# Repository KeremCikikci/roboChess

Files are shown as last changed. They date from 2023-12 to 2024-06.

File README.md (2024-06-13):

# RoboChess

vlcsnap-2023-12-28-12h02m27s572

https://www.youtube.com/watch?v=UMYv8-Q6y2Y
 
Each frame captured by the camera undergoes various processes to eliminate proportional distortions and noise. In the obtained output, each frame is observed individually and converted from BGR format to HSV format.

To reduce errors, colors of chess pieces that are far apart in the spectrum are made more distinguishable through different processes. Thus, the colors of the pieces on all squares are recorded. Since the positions of the pieces are known at the beginning of a chess game, there is no need to determine the types of pieces from the captured image.

For a chess game played on an online platform like Lichess, a unique ID is assigned to the game, and necessary information is retrieved using the Lichess API. However, to prevent cheating attempts, the Lichess API provides move information with a delay. Therefore, in a Lichess game, when a change occurs, a screenshot is taken to detect the move. Moves are recorded in the UCI (Universal Chess Interface) notation, which specifies the starting and ending coordinates of the pieces.

Additionally, the pieces obtained from Lichess at the beginning of the game are compared with the pieces detected in the squares from the camera. If they are not in sync, differing square coordinates are marked. When it's a player's turn, data flow is monitored from the Arduino, and if the button is pressed, the camera observes the pieces in the squares again. By identifying the differing pieces from the previously saved content, it's determined whether any piece has been captured. Then, a move notation is created in UCI format, and the move's validity is checked. The move is sent to the Lichess game with the assigned ID using the Lichess API. Additionally, time information obtained from the API is sent to Arduino via the Serial port.

At the start of each game, motors rotate until switches are triggered, bringing the robot arm to its home position. This resets all angle values and motors, enabling the robot arm to move to the desired coordinate in subsequent commands. After the home position, the arm moves to a waiting position. A function written in the Arduino code determines the slowest and fastest motor values on the arm, as well as the instantaneous speed during the motor's duty cycle, using a mathematical function.

While power is transmitted via a pulley on the X-axis, reducers are used on the Y and Z axes to greatly reduce the motor's speed and increase its torque by about 60 times. These reducers allow smooth movement of the load motors without excessive force.

In the final arm segment of the robot, there is a structure that lifts the chess pieces using a funnel. When triggered in the center of the funnel, a coil creates a magnetic field to lift the pieces by attracting the screws on top of them. Due to the high current drawn by the coil, it's triggered by a relay.

In the program, the chessboard is considered a coordinate axis, and after providing the coordinates where only the farthest point of the arm will be, the most economical angle values for the arm to reach the desired location are calculated. Motors bring the robot to the calculated angle values.

The movement path of the arm is determined by the move notation sent from the Serial monitor. When the arm movement is complete, it notifies the Python program. Additionally, time information is conveyed throughout the game. The remaining time of the opponents is visualised on displays. While each LED control of the displays requires 20 separate data wires, with 2 shift register chips, the data is transmitted using only 3 wires. The shift registers sequentially light up the required LEDs in each segment of the display. This process happens so quickly that the human eye perceives the LEDs as lit simultaneously.

## Run RoboChess
Install the necessary packages before running the code.
```
pip install -r requirements.txt
```

Before running the code, Arduino Uno must be connected to the computer and the `main.py` file must be configured.

+ Connect Arduino to your computer and specify its port
`ARDUINO_PORT = <your_arduino_port>`
+ Create a game from Lichess and assign the game link to the code.
`GAME_ID = <your_game_id>`
+ Position an external camera to see the chessboard and connect the camera to your computer.

Run the main code in the directory where you downloaded the repository.
```
python main.py
```

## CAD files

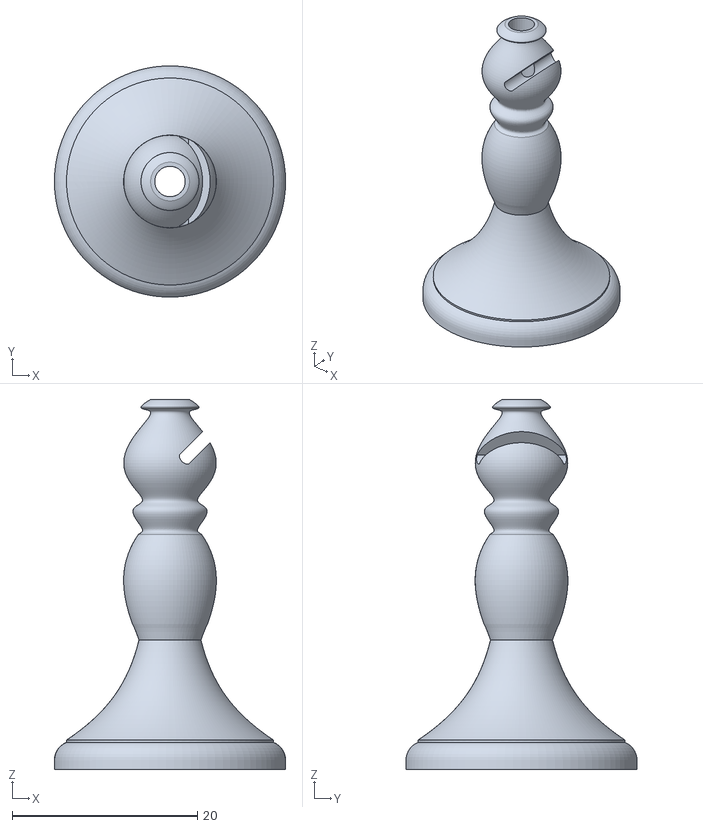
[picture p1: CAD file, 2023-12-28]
3D/chess_pieces/bishop.stl
25.0 x 25.0 x 40.0

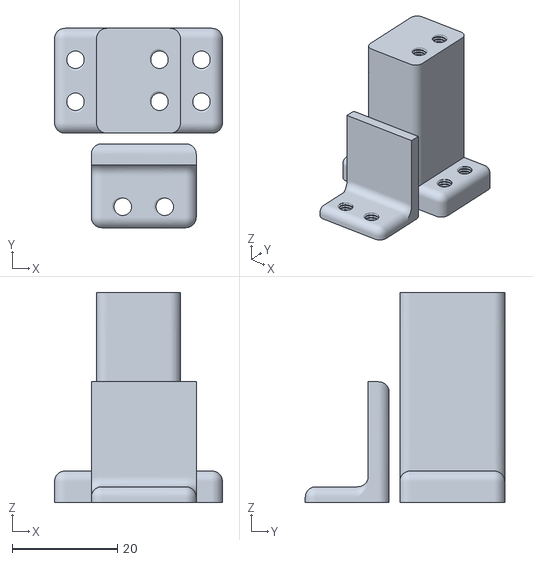
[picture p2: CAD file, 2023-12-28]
3D/main_elements/switchX_holder.stl
32.0 x 38.0 x 40.0

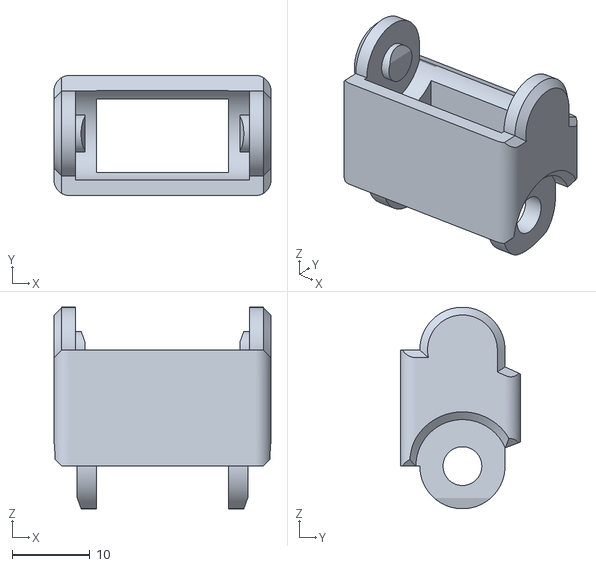
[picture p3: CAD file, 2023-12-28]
3D/others/cable_channel.stl
28.0 x 15.5 x 26.0

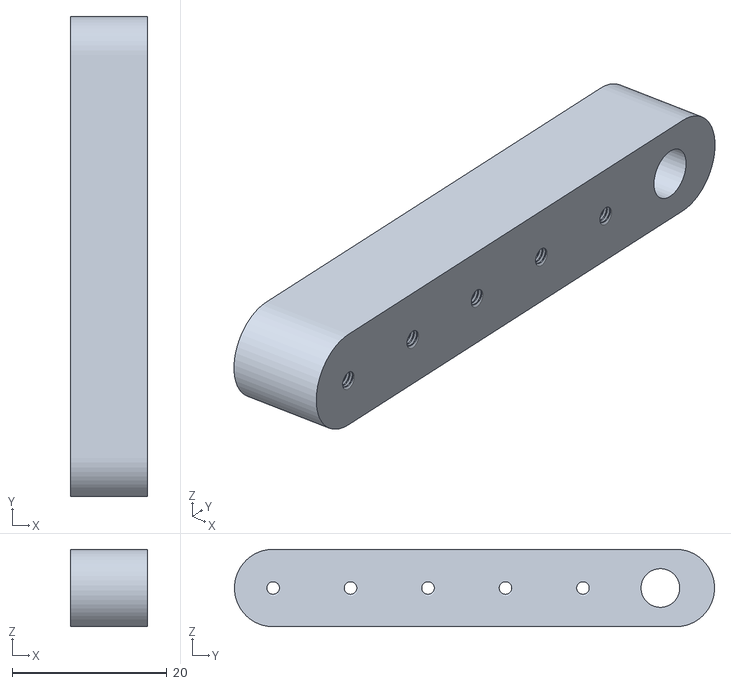
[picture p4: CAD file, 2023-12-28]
3D/reducer/radius1.stl
10.0 x 62.0 x 10.00

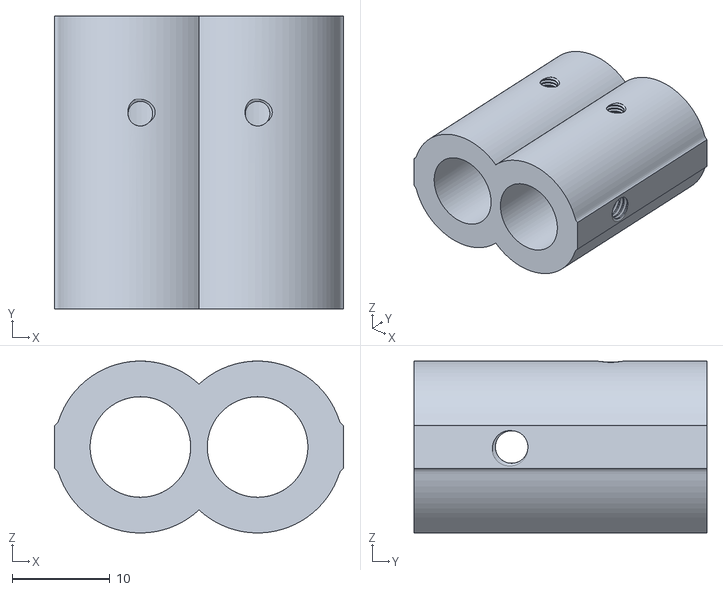
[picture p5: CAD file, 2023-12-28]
3D/third_arm/pipe_stabilizer.stl
29.6 x 30.0 x 17.6

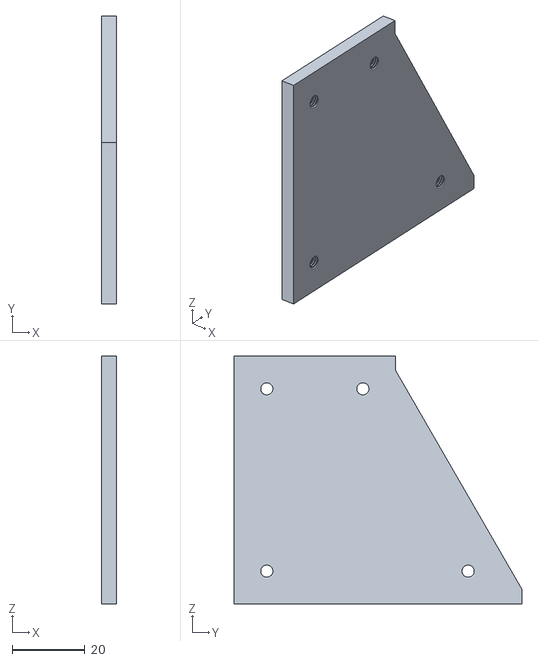
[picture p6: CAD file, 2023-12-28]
3D/watch_box/left.stl
4.00 x 79.0 x 68.0

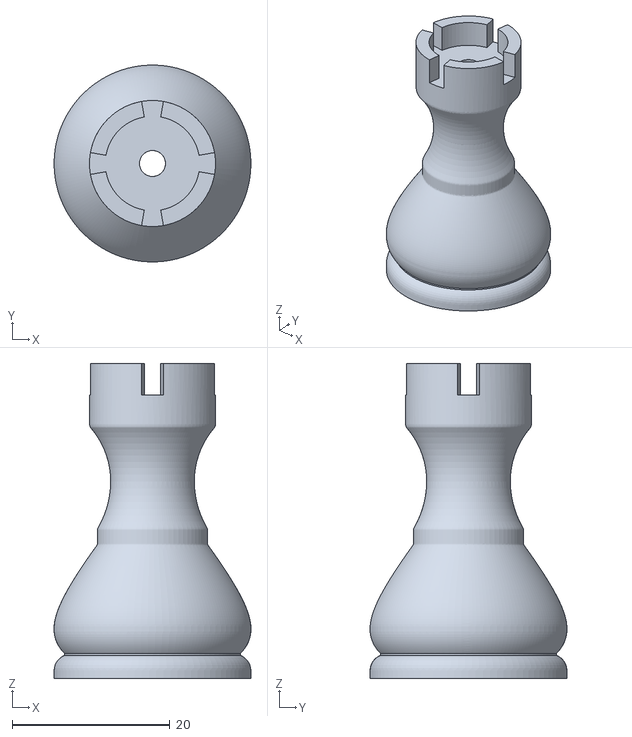
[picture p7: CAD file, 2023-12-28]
3D/chess_pieces/rook.stl
25.0 x 25.0 x 40.0

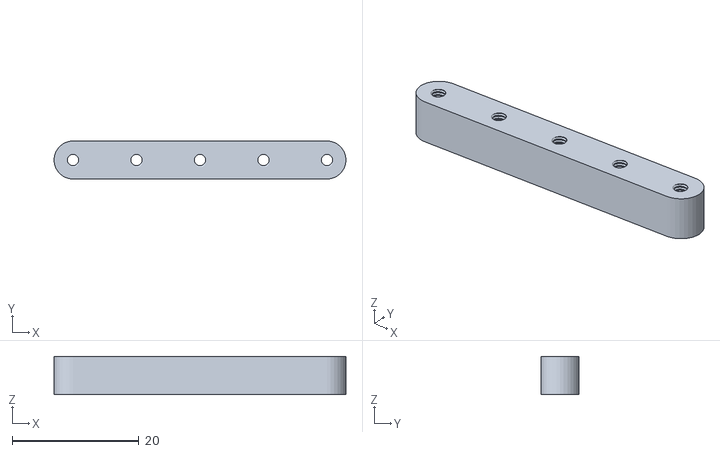
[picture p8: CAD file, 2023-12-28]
3D/main_elements/wire3.stl
46.0 x 6.00 x 6.00

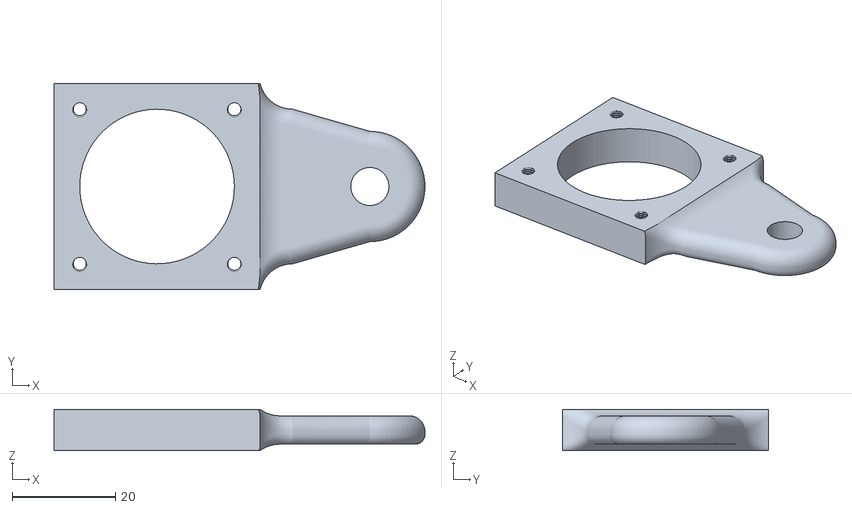
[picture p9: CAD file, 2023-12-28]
3D/others/cam_holder.stl
72.0 x 40.0 x 8.00

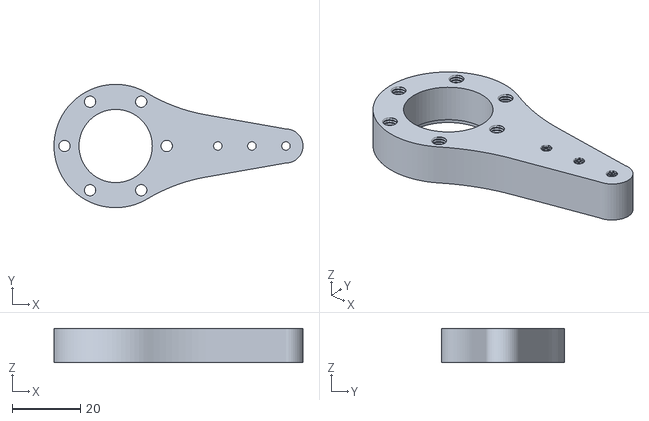
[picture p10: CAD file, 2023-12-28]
3D/reducer/reducer_out.stl
73.1 x 36.2 x 10.0

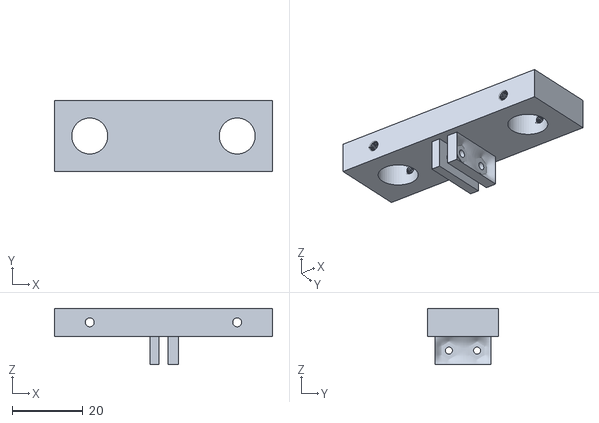
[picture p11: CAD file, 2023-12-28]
3D/third_arm/housing.stl
61.8 x 20.0 x 16.0

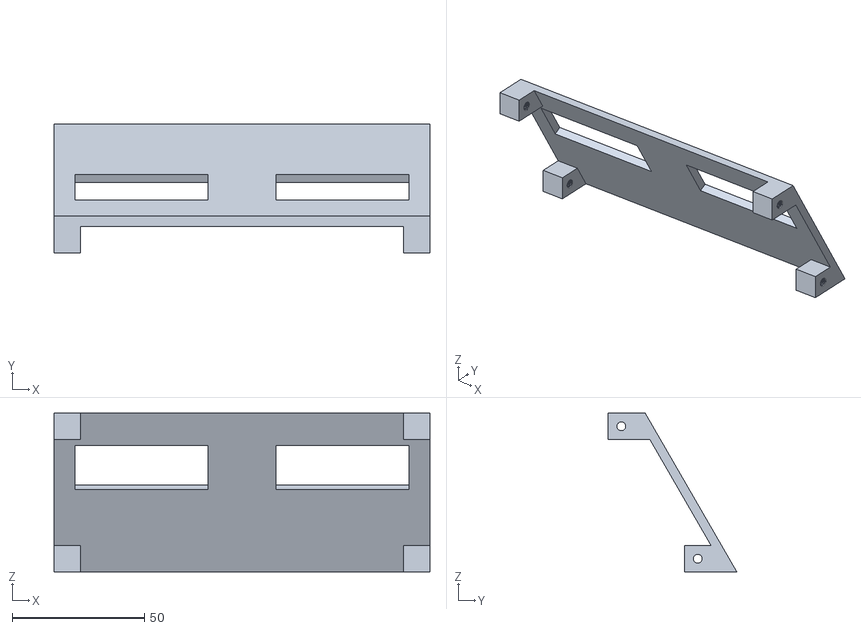
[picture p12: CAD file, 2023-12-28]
3D/watch_box/front.stl
142.0 x 48.6 x 60.0

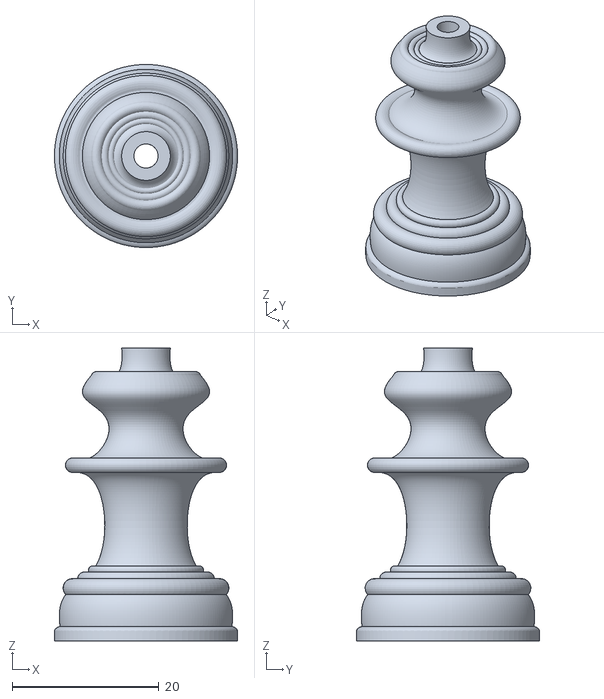
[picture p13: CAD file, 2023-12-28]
3D/chess_pieces/queen.stl
25.0 x 25.0 x 40.0

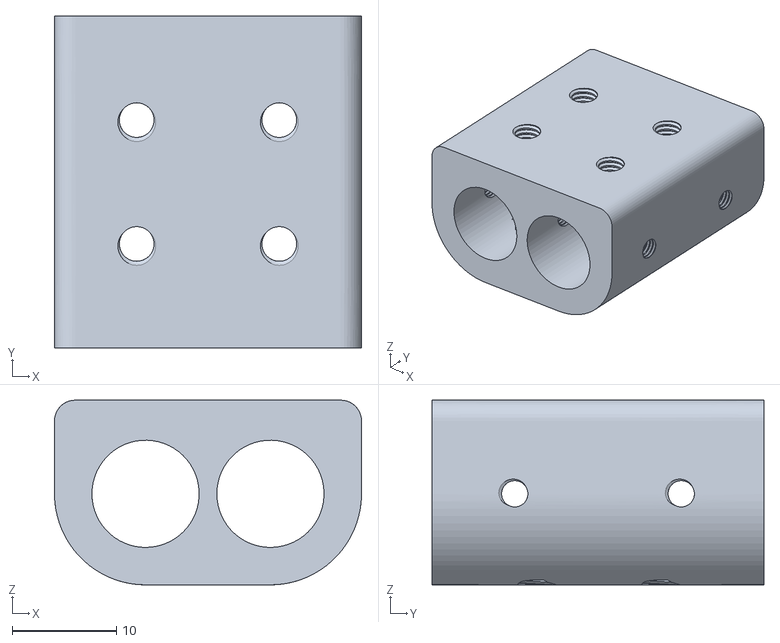
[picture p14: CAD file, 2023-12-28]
3D/main_elements/servo_base.stl
29.5 x 31.9 x 17.8

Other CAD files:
3D/others/light_holder.stl
3D/reducer/bpl.stl
3D/third_arm/coupling.stl
3D/watch_box/top.stl
3D/chess_pieces/king.stl
3D/chess_pieces/knight.stl
3D/chess_pieces/pawn.stl
3D/main_elements/base.stl
3D/main_elements/lower_bearing_seat.stl
3D/main_elements/nema17_holder v1.stl
3D/main_elements/nema17_holder v2.stl
3D/main_elements/nema17_holder v3.stl
3D/main_elements/pipe_stabilizer.stl
3D/main_elements/shaft_seat.stl
3D/main_elements/switchX_holder_top v2.stl
3D/main_elements/switchYholder.stl
3D/main_elements/top_bearing_seat.stl
3D/main_elements/wire.stl
3D/main_elements/wire2.stl
3D/main_elements/wire_holder.stl
3D/old_chess_pieces/bishop.stl
3D/old_chess_pieces/knight.stl
3D/old_chess_pieces/queen.stl
3D/old_chess_pieces/rook.stl
3D/old_gripper/gripper1 (1) v1.stl
3D/old_gripper/gripper1 (1) v8.stl
3D/old_gripper/gripper2 (1) v1.stl
3D/old_gripper/gripper2 (1) v3.stl
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

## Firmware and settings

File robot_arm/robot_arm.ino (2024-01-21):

#include <Servo.h>
Servo w;

#define dsP 13
#define latchP A5
#define clockP A4
#define button 12

#define gripper 8

#define dirX  2
#define pulseX 5
#define switchX A3
#define dirY 6
#define pulseY 7
#define switchY A1
#define dirZ  10
#define pulseZ 11
#define switchZ A2

boolean rotX = false; // false: go0
boolean rotY = true; // false: go0
boolean rotZ = true; // false: go0

double SPMX = 10.1;//9.5; // 9.75, 8.5
double SPDY = 28.89;//28.89
double SPDZ = 28.89;

double posX;
double angleA = 0;
double angleB = 0;
double angleC = 90;

int squaresA[8];
int squaresB[8];

int servoBost = 10;

int aAngles_[8][2] = {{118, 82}, {105, 74}, {95, 69}, {85, 62}, {78, 54}, {75, 46}, {60, 40}, {52, 30}};
int bAngles_[8][2] = {{45, 29}, {55, 43}, {55, 55}, {67, 66}, {82, 80}, {95, 93}, {115, 105}, {119, 117}};
int servoBosts[8] = {20, 18, 17, 12, 12, 10, 8, 10};

String alphabet[8] = {"a", "b", "c", "d", "e", "f", "g", "h"};

String move_ = "None";
String capture_ = "None";
String first, second, third, fourth;
int num1, num2;
double squareSize = 40;
double rightPadding = 40L;

String data;

unsigned int digits[8] = {32927, 16421, 8205, 4249, 2121, 1089, 539, 257};/*{0, 0, 0, 0, 0, 0, 0, 0};*/

String strBinDig;
String clock_;
String message;

String firstClock;
String secondClock;

boolean turn = true;

unsigned long previousMillis = 0;
const unsigned long interval = 1000;

String segments[10] = {
  "0000001", // 0
  "1001111", // 1
  "0010010", // 2
  "0000110", // 3
  "1001100", // 4
  "0100100", // 5
  "0100000", // 6
  "0001111", // 7
  "0000000", // 8
  "0000100"  // 9
};


void go0(int delay_){
  w.write(120);
  rotX = false; // false: go0
  rotY = false; // false: go0
  rotZ = false; // false: go0

  boolean switchXValue;
  boolean switchYValue;
  boolean switchZValue;
  
  digitalWrite(dirX, rotX);
  digitalWrite(dirY, rotY);
  digitalWrite(dirZ, rotZ);

  for(int i = 0; i < (int)(30 * SPDY); i++){
    switchYValue = digitalRead(switchY);
    digitalWrite(pulseY, 1);
    delayMicroseconds(delay_);
    digitalWrite(pulseY, 0);
    delayMicroseconds(delay_);

    if (switchYValue == 1)
      break;
  }
  
  while (true){
    switchXValue = digitalRead(switchX);
    switchYValue = digitalRead(switchY);
    switchZValue = digitalRead(switchZ);
    
    if (switchXValue == 0)
      digitalWrite(pulseX, 1);
      
    if (switchYValue == 0)
      digitalWrite(pulseY, 1);
    
    if (switchZValue == 0)
      digitalWrite(pulseZ, 1);
    
    delayMicroseconds(delay_);
    if (switchXValue == 0)
      digitalWrite(pulseX, 0);
    
    if (switchYValue == 0)
      digitalWrite(pulseY, 0);
    
    if (switchZValue == 0)
      digitalWrite(pulseZ, 0);
    
    if ((switchXValue == 1) && (switchYValue == 1) && (switchZValue == 1)){
      posX = 0;
      angleA = 123.7;//143.3
      angleB = 119;//108
      angleC = 90;

      break;
    }
    delayMicroseconds(delay_);
  }
  w.write(90);
}

int findMax(int a, int b, int c) {
  int maxVal = a;

  if (b > maxVal) {
    maxVal = b;
  }

  if (c > maxVal) {
    maxVal = c;
  }

  return maxVal;
}

void goPos(double xPosToGo, double aAngleToGo, double bAngleToGo, int minSpeed, int maxSpeed, int servoBost = 0){
  double deltaPosX = posX - xPosToGo;
  double deltaAngleA = angleA - aAngleToGo;
  double deltaAngleB = angleB - bAngleToGo;
  
  double posX_ = posX;
  double angleA_ = angleA;
  double angleB_ = angleB;
  
  int stepsX = abs(deltaPosX * SPMX);
  int stepsA = abs(deltaAngleA * SPDY);
  int stepsB = abs(deltaAngleB * SPDZ);

  int maxStep = findMax(stepsX, stepsA, stepsB);
  
  int steppedX = 0;
  int steppedA = 0;
  int steppedB = 0;
  
  double steppedAngleA = 0;
  double steppedAngleB = 0;

  rotX = true;
  rotY = false;
  rotZ = false;

  if (deltaPosX > 0)
    rotX = false;
  if (deltaAngleA > 0)
    rotY = true;
  if (deltaAngleB > 0)
    rotZ = true;

  digitalWrite(dirX, rotX);
  digitalWrite(dirY, rotY);
  digitalWrite(dirZ, rotZ);
    
  int phrase = 1;
  
  int lengthOfPhrase1 = maxStep/3;
  int lengthOfPhrase3 = maxStep/3;
  
  int delay_;

  int counter = 0;
  
  while (true){
    unsigned long currentMillis = millis();
    
    boolean switchXValue = digitalRead(switchX);
    boolean switchYValue = digitalRead(switchY);
    boolean switchZValue = digitalRead(switchZ);
/*
    if (((switchXValue == 1) || (switchYValue == 1) || (switchZValue == 1)) && (counter > 2000)){
      go0(500);
      break;
    }*/

    if (currentMillis - previousMillis >= interval) {
    previousMillis = currentMillis;

    if (turn == false){
      firstClock = String(firstClock.toInt()-1);
      int zeros = 4 - firstClock.length();
      for (int i = 0; i < zeros; i++){
        firstClock = "0" + firstClock;
      }
    }
    else{
      secondClock = String(secondClock.toInt()-1);
      int zeros = 4 - secondClock.length();
      for (int i = 0; i < zeros; i++){
        secondClock = "0" + secondClock;
      }
    }
    clock_ = formatTime(firstClock.toInt()) + formatTime(secondClock.toInt());
    formatClock();
  }
  
    counter++;
    
    stepsX--;
    stepsA--;
    stepsB--;

    if ((steppedX > maxStep - lengthOfPhrase3) || (steppedA > maxStep - lengthOfPhrase3) || (steppedB > maxStep - lengthOfPhrase3))
      phrase = 3;
    else if ((steppedX > lengthOfPhrase1) || (steppedA > lengthOfPhrase1) || (steppedB > lengthOfPhrase1))
      phrase = 2;

    if (phrase == 3)
      delay_ = map(counter, maxStep - lengthOfPhrase3, maxStep, maxSpeed, minSpeed);
    if (phrase == 2)
      delay_ = maxSpeed;
    if (phrase == 1)
      delay_ = map(counter, 0, lengthOfPhrase1, minSpeed, maxSpeed);
    
    if (stepsX >= 0){
      digitalWrite(pulseX, 1); 
    }
       
    if (stepsA >= 0){
      digitalWrite(pulseY, 1);
    }
      
    if (stepsB >= 0){
      digitalWrite(pulseZ, 1);
    }
      
    delayMicroseconds(delay_);

    if (stepsX >= 0){
      digitalWrite(pulseX, 0);
      steppedX++;
    }
    if (stepsA >= 0){
      digitalWrite(pulseY, 0);
      steppedA++;
    }
    if (stepsB >= 0){
      digitalWrite(pulseZ, 0);
      steppedB++;
    }
    
    if ((stepsX < 0) && (stepsA < 0) && (stepsB < 0)){
      posX = xPosToGo;
      angleA = aAngleToGo;
      angleB = bAngleToGo;
      
      break;
    }

    steppedAngleA = steppedA / SPDY;
    steppedAngleB = steppedB / SPDZ;

    if (rotX == false)
      posX = posX + steppedX;
    else
      posX = posX - steppedX;
      
    if (rotY == false)
      angleA = angleA_ + steppedAngleA;
    else
      angleA = angleA_ - steppedAngleA;

    if (rotZ == false)
      angleB = angleB_ + steppedAngleB;
    else
      angleB = angleB_ - steppedAngleB;

    angleC = 270 - angleA - angleB;

    if ((angleC > 60) && (angleC < 160))
      w.write(angleC + servoBost);
      //Serial.println(angleC);
    delayMicroseconds(delay_);
  }
  posX = xPosToGo;
  angleA = aAngleToGo;
  angleB = bAngleToGo;
}
void goPos2(double xPosToGo, double aAngleToGo, double bAngleToGo, int minSpeed, int maxSpeed, int servoBost = 0){
  double deltaPosX = posX - xPosToGo;
  double deltaAngleA = angleA - aAngleToGo;
  double deltaAngleB = angleB - bAngleToGo;
  
  double posX_ = posX;
  double angleA_ = angleA;
  double angleB_ = angleB;
  
  int stepsX = abs(deltaPosX * SPMX);
  int stepsA = abs(deltaAngleA * SPDY);
  int stepsB = abs(deltaAngleB * SPDZ);

  int maxStep = findMax(stepsX, stepsA, stepsB);
  
  int steppedX = 0;
  int steppedA = 0;
  int steppedB = 0;
  
  double steppedAngleA = 0;
  double steppedAngleB = 0;

  rotX = true;
  rotY = false;
  rotZ = false;

  if (deltaPosX > 0)
    rotX = false;
  if (deltaAngleA > 0)
    rotY = true;
  if (deltaAngleB > 0)
    rotZ = true;

  digitalWrite(dirX, rotX);
  digitalWrite(dirY, rotY);
  digitalWrite(dirZ, rotZ);
    
  int phrase = 1;
  
  int lengthOfPhrase1 = maxStep/3;
  int lengthOfPhrase3 = maxStep/3;
  
  int delay_;

  int counter = 0;
  
  while (true){
    unsigned long currentMillis = millis();
    
    boolean switchXValue = digitalRead(switchX);
    boolean switchYValue = digitalRead(switchY);
    boolean switchZValue = digitalRead(switchZ);
/*
    if (((switchXValue == 1) || (switchYValue == 1) || (switchZValue == 1)) && (counter > 2000)){
      go0(500);
      break;
    }*/

    if (currentMillis - previousMillis >= interval) {
    previousMillis = currentMillis;

    if (turn == false){
      firstClock = String(firstClock.toInt()-1);
      int zeros = 4 - firstClock.length();
      for (int i = 0; i < zeros; i++){
        firstClock = "0" + firstClock;
      }
    }
    else{
      secondClock = String(secondClock.toInt()-1);
      int zeros = 4 - secondClock.length();
      for (int i = 0; i < zeros; i++){
        secondClock = "0" + secondClock;
      }
    }
    clock_ = formatTime(firstClock.toInt()) + formatTime(secondClock.toInt());
    formatClock();
  }
  
    counter++;
    
    stepsX--;
    stepsA--;
    stepsB--;

    if ((steppedX > maxStep - lengthOfPhrase3) || (steppedA > maxStep - lengthOfPhrase3) || (steppedB > maxStep - lengthOfPhrase3))
      phrase = 3;
    else if ((steppedX > lengthOfPhrase1) || (steppedA > lengthOfPhrase1) || (steppedB > lengthOfPhrase1))
      phrase = 2;

    if (phrase == 3)
      delay_ = map(counter, maxStep - lengthOfPhrase3, maxStep, maxSpeed, minSpeed);
    if (phrase == 2)
      delay_ = maxSpeed;
    if (phrase == 1)
      delay_ = map(counter, 0, lengthOfPhrase1, minSpeed, maxSpeed);
    
    if (stepsX >= 0){
      digitalWrite(pulseX, 1); 
    }
       
    if (stepsA >= 0){
      digitalWrite(pulseY, 1);
    }
      
    if (stepsB >= 0){
      digitalWrite(pulseZ, 1);
    }
      
    delayMicroseconds(delay_);

    if (stepsX >= 0){
      digitalWrite(pulseX, 0);
      steppedX++;
    }
    if (stepsA >= 0){
      digitalWrite(pulseY, 0);
      steppedA++;
    }
    if (stepsB >= 0){
      digitalWrite(pulseZ, 0);
      steppedB++;
    }
    
    if ((stepsX < 0) && (stepsA < 0) && (stepsB < 0)){
      posX = xPosToGo;
      angleA = aAngleToGo;
      angleB = bAngleToGo;
      
      break;
    }

    steppedAngleA = steppedA / SPDY;
    steppedAngleB = steppedB / SPDZ;

    if (rotX == false)
      posX = posX + steppedX;
    else
      posX = posX - steppedX;
      
    if (rotY == false)
      angleA = angleA_ + steppedAngleA;
    else
      angleA = angleA_ - steppedAngleA;

    if (rotZ == false)
      angleB = angleB_ + steppedAngleB;
    else
      angleB = angleB_ - steppedAngleB;

    angleC = 270 - angleA - angleB;

    if ((angleC > 60) && (angleC < 160))
      //w.write(angleC + servoBost);
      //Serial.println(angleC);
    delayMicroseconds(delay_);
    w.write(50);
  }
  posX = xPosToGo;
  angleA = aAngleToGo;
  angleB = bAngleToGo;
}
int findIndexOfChar(String str, String target) {
  int strLength = str.length();
  int targetLength = target.length();
  
  for (int i = 0; i <= strLength - targetLength; i++) {
    if (str.substring(i, i + targetLength) == target) {
      return i; // Eğer hedef string bulunursa indeksi döndür
    }
  }
  
  return -1;
}
int findIndexOfStringInList(String list[], String targetString) {
  for (int i = 0; i < 8; i++) {
    if (list[i] == targetString) {
      return i; // String karakterini içeren stringin indeksini döndür
    }
  }
  return -1; // String karakterini içeren string bulunamazsa -1 döndür
}
void formatClock(){
  for (int i = 0; i < clock_.length(); i++) {
        // pre 0 s
        for (int pre0s = 0; pre0s < i; pre0s++){
          strBinDig.concat("0");
        }
        // 1
        strBinDig.concat("1");
        // post 0 s
        for (int post0s = 0; post0s < clock_.length() - i - 1; post0s++){
          strBinDig.concat("0");
        }
        strBinDig.concat(segments[clock_.charAt(i) - '0']);
        // point
        if ((i == 1) || (i == 5)){
          strBinDig.concat("0");
        }
        else{
          strBinDig.concat("1");
        }
        long decDig = strtol(strBinDig.c_str(), NULL, 2);
        digits[i] = decDig;
        strBinDig = "";
      }
}

String formatTime(unsigned int totalSeconds) {
  unsigned int minutes = totalSeconds / 60;
  unsigned int seconds = totalSeconds % 60;

  String formattedTime = "";

  if (minutes < 10) {
    formattedTime += "0";
  }
  formattedTime += String(minutes);

  if (seconds < 10) {
    formattedTime += "0";
  }
  formattedTime += String(seconds);

  return formattedTime;
}

void setup(){
  pinMode(dsP, OUTPUT);
  pinMode(latchP, OUTPUT);
  pinMode(clockP, OUTPUT);
  pinMode(button, INPUT);
  
  pinMode(dirX, OUTPUT);
  pinMode(pulseX, OUTPUT);
  pinMode(switchX, INPUT);
  pinMode(dirY, OUTPUT);
  pinMode(pulseY, OUTPUT);
  pinMode(switchY, INPUT);
  pinMode(dirZ, OUTPUT);
  pinMode(pulseZ, OUTPUT);
  pinMode(switchZ, INPUT);
  pinMode(gripper, OUTPUT);
  w.attach(9);
  digitalWrite(gripper, 0);

  Serial.begin(115200);
  Serial.setTimeout(1);
  digitalWrite(dirX, rotX);
  digitalWrite(dirY, rotY);
  digitalWrite(dirZ, rotZ);
  
  /*
  Manneall Stepper Starter

  for(int i = 0; i < (int)(SPDY * 100); i++){
    digitalWrite(dirY, 1);
    digitalWrite(pulseY, 1);
    delayMicroseconds(500);
    digitalWrite(pulseY, 0);
    delayMicroseconds(500);
  }*/
/*
  for(int i = 0; i < (int)(SPDZ * 360); i++){
    digitalWrite(dirZ, 1);
    digitalWrite(pulseZ, 1);
    delayMicroseconds(500);
    digitalWrite(pulseZ, 0);
    delayMicroseconds(500);
  }*/
  go0(500);
  digitalWrite(gripper,0);
  goPos(0, 90, 90, 1000, 400, 0);
  w.write(90);
  //goPos(200, 35.51, 74, 200, 600);
}


void loop(){
  unsigned long currentMillis = millis();
  
  if (digitalRead(button) == 0){
    delay(250);
    if (digitalRead(button) == 0){
      Serial.println("move");
    }
  }
      
      
  if (Serial.available() > 0){
    delay(100);
    if (Serial.available() > 0){
      data =  Serial.readStringUntil('\n');
      Serial.println("O");
      // clock
      if (data.length() == 8){
        if (turn == true)
          turn = false;
        else
          turn = true;
        
        firstClock = data.substring(0, 4);
        secondClock = data.substring(4);
        clock_ = formatTime(firstClock.toInt()) + formatTime(secondClock.toInt());
        Serial.println(clock_);
        formatClock();
      }
      // Show Move
      // Castles
      else if (data == "S"){
        // 1. Square 
        digitalWrite(gripper, 0);
        goPos(180 + rightPadding, aAngles_[0][0], bAngles_[0][0], 1000, 400, servoBosts[0]);
        digitalWrite(gripper, 1);
        delay(250);
        goPos(180 + rightPadding, aAngles_[0][1], bAngles_[0][1], 1800, 1200, servoBosts[0]);
        delay(250);
        goPos(180 + rightPadding, aAngles_[0][0], bAngles_[0][0], 1800, 1200, servoBosts[0]);
        delay(250);
        
        // 3. Square
        goPos(260 + rightPadding, aAngles_[0][0], bAngles_[0][0], 1000, 400, servoBosts[0]);
        delay(250);
        goPos(260 + rightPadding, aAngles_[0][1], bAngles_[0][1], 1800, 1200, servoBosts[0]);
        digitalWrite(gripper, 0);
        delay(250);
        goPos(260 + rightPadding, aAngles_[0][0], bAngles_[0][0], 1800, 1200, servoBosts[0]);
        delay(250);

        // 4. Square
        goPos(300 + rightPadding, aAngles_[0][0], bAngles_[0][0], 1000, 400, servoBosts[0]);
        digitalWrite(gripper, 1);
        delay(250);
        goPos(300 + rightPadding, aAngles_[0][1], bAngles_[0][1], 1800, 1200, servoBosts[0]);
        delay(250);
        goPos(300 + rightPadding, aAngles_[0][0], bAngles_[0][0], 1800, 1200, servoBosts[0]);
        delay(250);
        
        // 2. Square
        goPos(220 + rightPadding, aAngles_[0][0], bAngles_[0][0], 1000, 400, servoBosts[0]);
        delay(250);
        goPos(220 + rightPadding, aAngles_[0][1], bAngles_[0][1], 1800, 1200, servoBosts[0]);
        digitalWrite(gripper, 0);
        delay(250);
        goPos(220 + rightPadding, aAngles_[0][0], bAngles_[0][0], 1800, 1200, servoBosts[0]);
        delay(250);

        goPos(0, 90, 90, 1000, 400, 0);
      }

      else if (data == "L"){
        // 4. Square 
        digitalWrite(gripper, 0);
        goPos(20 + rightPadding, aAngles_[0][0], bAngles_[0][0], 1000, 400, servoBosts[0]);
        digitalWrite(gripper, 1);
        delay(250);
        goPos(20 + rightPadding, aAngles_[0][1], bAngles_[0][1], 1800, 1200, servoBosts[0]);
        delay(250);
        goPos(20 + rightPadding, aAngles_[0][0], bAngles_[0][0], 1800, 1200, servoBosts[0]);
        delay(250);
        
        // 6. Square
        goPos(140 + rightPadding, aAngles_[0][0], bAngles_[0][0], 1000, 400, servoBosts[0]);
        delay(250);
        goPos(140 + rightPadding, aAngles_[0][1], bAngles_[0][1], 1800, 1200, servoBosts[0]);
        digitalWrite(gripper, 0);
        delay(250);
        goPos(140 + rightPadding, aAngles_[0][0], bAngles_[0][0], 1800, 1200, servoBosts[0]);
        delay(250);

        // 8. Square
        goPos(180 + rightPadding, aAngles_[0][0], bAngles_[0][0], 1000, 400, servoBosts[0]);
        digitalWrite(gripper, 1);
        delay(250);
        goPos(180 + rightPadding, aAngles_[0][1], bAngles_[0][1], 1800, 1200, servoBosts[0]);
        delay(250);
        goPos(180 + rightPadding, aAngles_[0][0], bAngles_[0][0], 1800, 1200, servoBosts[0]);
        delay(250);
        
        // 5. Square
        goPos(100 + rightPadding, aAngles_[0][0], bAngles_[0][0], 1000, 400, servoBosts[0]);
        delay(250);
        goPos(100 + rightPadding, aAngles_[0][1], bAngles_[0][1], 1800, 1200, servoBosts[0]);
        digitalWrite(gripper, 0);
        delay(250);
        goPos(100 + rightPadding, aAngles_[0][0], bAngles_[0][0], 1800, 1200, servoBosts[0]);
        delay(250);

        goPos(0, 90, 90, 1000, 400, 0);
      }
      
      else if (((data == "M") && (move_ != "None")) || ((data == "C") && (move_ != "None"))){
        num1 = second.toInt() - 1;
        num2 = fourth.toInt() - 1;

        // 1. High
        double x1 = findIndexOfStringInList(alphabet, first) * squareSize + squareSize / 2 + rightPadding;
        int y1 = num1;
        double a1Y = aAngles_[y1][0];
        double b1Y = bAngles_[y1][0];

        // 1. Low
        double a1A = aAngles_[y1][1];
        double b1A = bAngles_[y1][1];

        // 2. High
        double x2 = findIndexOfStringInList(alphabet, third) * squareSize + squareSize / 2 + rightPadding;
        int y2 = num2;
        double a2Y = aAngles_[y2][0];
        double b2Y = bAngles_[y2][0];

        // 2. Low
        double a2A = aAngles_[y2][1];
        double b2A = bAngles_[y2][1];
        
        // Move
        // If Capture
        if (data == "C"){
          // 2. Square
          digitalWrite(gripper, 0);
          goPos(x2, a2Y, b2Y, 1000, 400, servoBosts[y2 ]);
          delay(250);
          digitalWrite(gripper, 1);

          // Take 2
          goPos(x2, a2A, b2A, 1800, 1200, servoBosts[y2 ]);
          delay(250);
          goPos(x2, a2Y, b2Y, 1800, 1200, servoBosts[y2 ]);
          delay(250);

          // Remove
          goPos(0, 65, 90, 1000, 400, 0);
          delay(250);
          digitalWrite(gripper, 0);
        }
        
        // 1. Square
        digitalWrite(gripper, 0);
        delay(250);
        goPos(x1, a1Y, b1Y, 1000, 400, servoBosts[y1 ]);
        delay(250);

        // Take 1
        digitalWrite(gripper, 1);
        delay(250);
        goPos(x1, a1A, b1A, 1800, 1000, servoBosts[y1 ]);
        delay(250);
        goPos(x1, a1Y, b1Y, 1800, 1000, servoBosts[y1 ]);
        delay(250);

        // 2. Square
        goPos(x1, a2Y, b2Y, 600, 400, servoBosts[y2 ]);
        goPos(x2, a2Y, b2Y, 600, 400, servoBosts[y2 ]);
        delay(250);
        
        // 2. Drop;
        goPos(x2, a2A, b2A, 1800, 1000, servoBosts[y2 ]);
        delay(250);
        digitalWrite(gripper, 0);
        delay(1000);
        goPos(x2, a2Y, b2Y, 1800, 1000, servoBosts[y2 ]);
        delay(250);
        goPos(0, 90, 90, 600, 400, 0);
        delay(250);
        
        
        move_ = "None";
      }
      
      // Fetch the Move
      else if (data.length() == 4){
        move_ = data;

        first = move_.substring(0, 1);
        second = move_.substring(1, 2);
        third = move_.substring(2, 3);
        fourth = move_.substring(3, 4);
      }
    }
  }
  for (int i = 0; i < 8; i++){
    byte lowLED  = lowByte(digits[i]);
    byte highLED = highByte(digits[i]);
    
    digitalWrite(latchP, 0);
    
    shiftOut(dsP, clockP, LSBFIRST, lowLED);
    shiftOut(dsP, clockP, LSBFIRST, highLED);
    
    digitalWrite(latchP, 1);
    delay(2);
  }
  if (currentMillis - previousMillis >= interval) {
    previousMillis = currentMillis;

    if (turn == false){
      firstClock = String(firstClock.toInt()-1);
      int zeros = 4 - firstClock.length();
      for (int i = 0; i < zeros; i++){
        firstClock = "0" + firstClock;
      }
    }
    else{
      secondClock = String(secondClock.toInt()-1);
      int zeros = 4 - secondClock.length();
      for (int i = 0; i < zeros; i++){
        secondClock = "0" + secondClock;
      }
    }
    clock_ = formatTime(firstClock.toInt()) + formatTime(secondClock.toInt());
    formatClock();
  }
}

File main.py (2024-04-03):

import numpy as np
import cv2
import json
import copy
import berserk
from colorama import init, Fore, Style
from datetime import timedelta, datetime
import time
import serial
from ultralytics import YOLO

import functions as func

init(autoreset=True)

### CONSTANTS ###
GAME_ID = 'P5JOI8sD'
ARDUINO_PORT = 'COM6'
VIDEO_DEVICE = 0
GAMER = "WHITE"

# For the Old Color Detection Function
midDefPerBlack = 12
midDefPerWhite = 2
showDetails = False

color_threshold = .25
color_threshold_lichess = .1

whiteTreshold = .12
blackTreshold = .1


width, height = 800, 800
squareWidth, squareHeight = int(width / 8), int(height / 8)
horizontal = ['h', 'g', 'f', 'e', 'd', 'c', 'b', 'a']

path = "squares/"

button_trigger = datetime.now()

### ON THE CHESSBOARD ###
# They are not used in the current version
lowerBoardWhite_hsv, upperBoardWhite_hsv = (50, 30, 150), (255, 250, 255)
lowerBoardBlack_hsv, upperBoardBlack_hsv = (120, 30, 20), (150, 205, 70)

lowerWhite_hsv = (0, 0, 50)
upperWhite_hsv = (5, 3, 255)
lowerBlack_hsv = (0, 0, 0)
upperBlack_hsv = (5, 3, 50)

rival = 'WHITE'
if GAMER == 'WHITE':
    rival = 'BLACK'

### VARIABLES ###
contents = [[None] * 8 for _ in range(8)]
liContents = [[None] * 8 for _ in range(8)]
turn = GAMER

### CALIBRATIONS ###
### Calibrate Corners ###
#func.calibCorner()

### Calibrate Board ###
#func.calibBoard(width, height)

### INITIATE ARDUINO ###
arduino = serial.Serial(port=ARDUINO_PORT, baudrate=115200, timeout=0)

### FETCH SETTINGS ###
with open('settings.json', 'r') as file:
    data = json.load(file)

assert "references" in data, "references data is missing!"
references = data['references']

assert "corners" in data, "corners data is missing!"
pts1 = np.float32(data["corners"])

pts2 = np.float32([[0, 0], [width, 0], [0, height], [width, height]])
matrix = cv2.getPerspectiveTransform(pts1, pts2)

cam = cv2.VideoCapture(VIDEO_DEVICE)
model = YOLO('best.pt')

### LICHESS ###
API_TOKEN = 'lip_LaYVt0nOKwUnjEv1gJSZ'
session = berserk.TokenSession(API_TOKEN)
client = berserk.Client(session=session)

x1, y1, x2, y2 = 400, 160, 905, 670

### MATCH THE BOARDS ###
ret, board = cam.read()
cv2.imwrite("board.jpg", board)
board = cv2.warpPerspective(board, matrix, (width, height))

for x in range(8):
    for y in range(8):
        square = board[int(y * squareHeight):int((y+1) * squareHeight), int(x * squareWidth):int((x+1)*squareWidth)]
        
        contents[7-x][y] = func.detectColor(square, model)

        # Old Color Detection Functions

        #contents[7-x][y] = func.detectColor(square, lowerBoardWhite_hsv, upperBoardWhite_hsv, lowerBoardBlack_hsv, upperBoardBlack_hsv, whiteTreshold, blackTreshold)
        #contents[7-x][y] = func.colorDetect(square, references[x][y], midDefPerBlack, midDefPerWhite, vis=showDetails)
        #contents[7-x][y] = func.colorDetect2(square, lowerBoardWhite_hsv, upperWhite_hsv, lowerBlack_hsv, upperBlack_hsv, color_threshold, vis=showDetails)
        
        cv2.imwrite(path+horizontal[x]+str(y+1)+'.jpg', square)
liContents = func.detectLiContents(lowerWhite_hsv, upperWhite_hsv, lowerBlack_hsv, upperBlack_hsv, color_threshold_lichess, x1, y1, x2, y2)

print(contents, liContents)

if liContents == contents:
    print_ = "Boards are synchronous ✔"
    print(f"{Fore.GREEN}{print_}{Style.RESET_ALL}")
else:
    print_ = "Boards are not synchronous ✗"
    print(f"{Fore.RED}{print_}{Style.RESET_ALL}")

    differences = []
    for i in range(len(contents)):
        for j in range(len(contents[i])):
            if contents[i][j] != liContents[i][j]:
                differences.append([i, j])

    for i, j in differences:
        _1 = contents[i][j]
        _2 = liContents[i][j]
        format_1 = f"{Fore.RED}{_1}{Style.RESET_ALL}"
        format_2 = f"{Fore.RED}{_2}{Style.RESET_ALL}"
        print(f"({i}, {j}): {format_1} (Chess Board) -> {format_2} (Lichess)")

while True:
    button_time = datetime.now()

    move = None
    captured = None
    changes = []

    if turn == GAMER:
        #nextMove = input() ##### => If button is not active
        try:
            #pass
            read = arduino.readline().decode().strip()
        except:
            pass
        else:
            if len(read) > 1:
                print(read)
            if read == 'move' and button_time > button_trigger:
            #if 1 == 1: -> Placeholder
                button_trigger = button_time + timedelta(seconds=1)
                
                ret, board = cam.read()
                
                board = cv2.warpPerspective(board, matrix, (width, height))

                newContents = copy.deepcopy(contents)
                #print("check1")
                
                for x in range(8):
                    for y in range(8):
                        square = board[int(y * squareHeight):int((y+1) * squareHeight), int(x * squareWidth):int((x+1)*squareWidth)]

                        contents[7-x][y] = func.detectColor(square, model)

                        # They are not used in the current version
                        #contents[7-x][y] = func.detectColor(square, lowerBoardWhite_hsv, upperBoardWhite_hsv, lowerBoardBlack_hsv, upperBoardBlack_hsv, whiteTreshold, blackTreshold)
                        #contents[7-x][y] = func.colorDetect(square, references[x][y], midDefPerBlack, midDefPerWhite, vis=showDetails)
                
                        cv2.imwrite(path+horizontal[x]+str(y+1)+'.jpg', square)

                changes = func.detectChanges(newContents, contents)

                print(changes)

                if len(changes) == 2 or len(changes) == 4: # for better result set it > 0
                    move, captured = func.detectMove(changes, newContents, contents)
                    
                    print(move, captured)
                    
                    # CASTLING
                    if move == "KISA":
                        if GAMER == "BLACK":
                            move = "e8g8"
                        else:
                            move = "e1g1"
                    elif move == "UZUN":
                        if GAMER == "BLACK":
                            move = "e8c8"
                        else:
                            move = "e1c1"

                    for i in range(20):
                        try:
                            berserk.clients.Board(session=session).make_move(GAME_ID, move)            
                        except berserk.exceptions.ResponseError as e:
                            print(e)
                        else:
                            #print("check2")
                            #print(contents, newContents)

                            #contents = copy.deepcopy(newContents)
                            #liContents = copy.deepcopy(newContents)
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
